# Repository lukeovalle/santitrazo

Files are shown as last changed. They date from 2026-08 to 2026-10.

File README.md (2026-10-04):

# Santitrazo
Seguidor de línea usando un atmega328p

## Estructura del directorio
placa/      proyecto de KiCAD
codigo/     código de Arduino
cuerpo/     piezas mecánicas (FreeCAD + STL)

## TODO
 - [ ] describir mejor el proyecto

## Mediciones 
Placa + sensores
    5V 0.9A
    
Motores
    5V  0.3A
    6V  1.3A

## Valores PID
Historial de pruebas. Los valores vigentes en el firmware están en las constantes
`k_prop`, `k_inte` y `k_dif` de `codigo/TaskController.cpp`.

P    | I      | D   | tiempo | pista grande
0.85 | 1e-3   | 6   | 4.6    |
0.9  | 2e-3   | 6   | 4.8    | 28
0.95 | 1.2e-3 | 6.2 | 5.2    |
0.85 | 1e-3   | 6   | --     | 27.88
0.92 | 1.2e-3 | 6.1 | 5.2    |
0.92 | 1.2e-3 | 6.1 | 4.7    | 28.3 (rigidizar ruedas traseras, lubricar placa, bat 7,1 V)
1    | 1.2e-3 | 6.2 | ------ |     (bat 7,8 V)
1.1  | 1.2e-3 | 6.8 | 5.7    |     (bat 7,8 V)
1    | 1.2e-3 | 3   | 4.6    |  (07/08/26 PID cada 10ms, promediado de sensores)
1.05 | 1.2e-3 | 5   | 4.6    | 
1.1  | 1.2e-3 | 6   | 4.4    |
1.1  | 1.5e-3 | 7   | 4.4    |
1.1  | 1.5e-3 | 8   | 4.4    | 24.3  (8.14V)

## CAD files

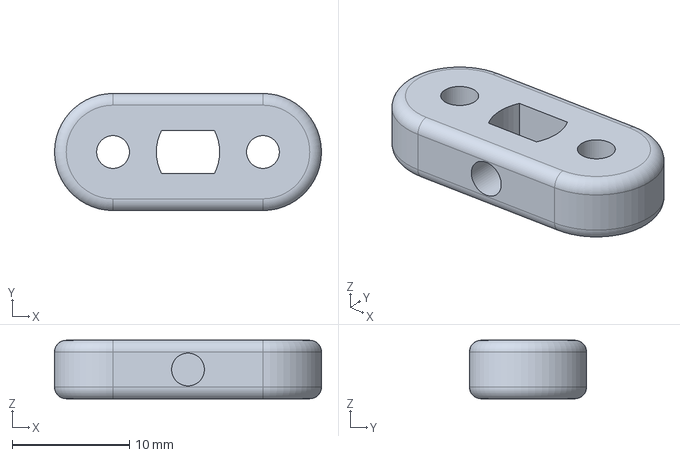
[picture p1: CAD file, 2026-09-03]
cuerpo/adaptador_motor_rueda.FCStd
22.8 x 10.0 x 5.00 mm

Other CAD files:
cuerpo/adaptador_motor_rueda-Body.stl

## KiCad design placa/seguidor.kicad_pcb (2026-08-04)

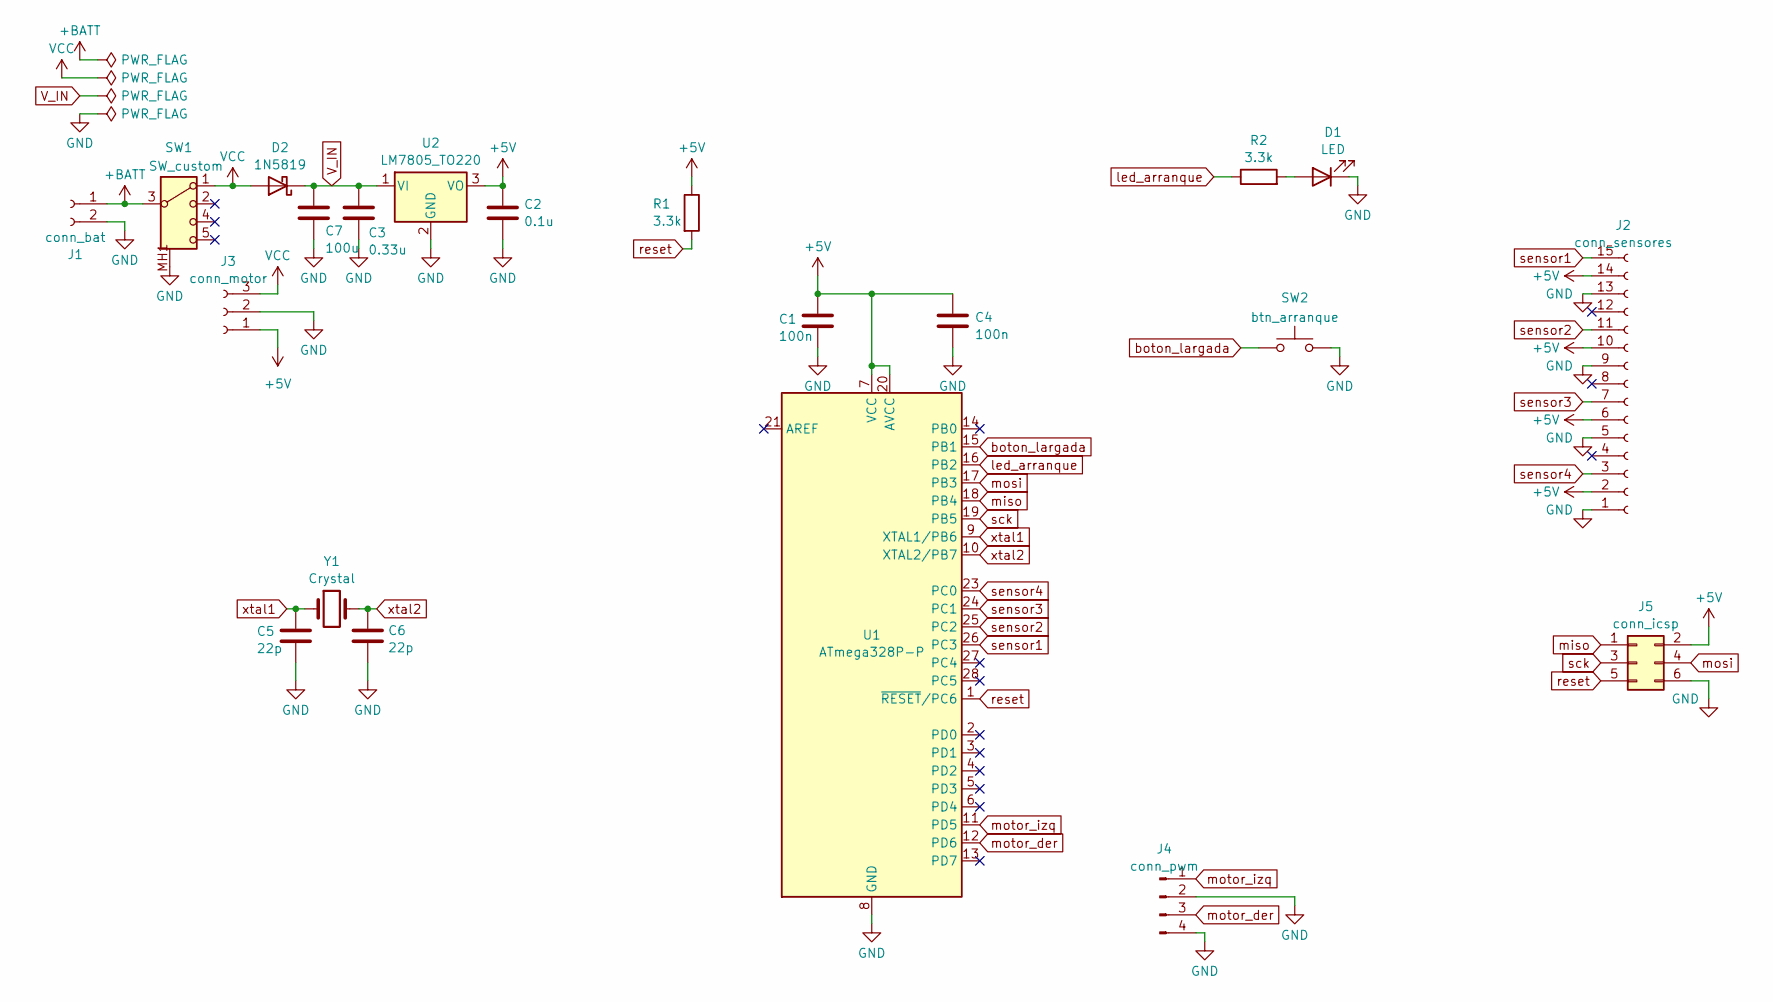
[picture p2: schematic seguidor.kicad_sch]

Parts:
C1, C4: 100n; C_Disc_D6.0mm_W2.5mm_P5.00mm
C2: 0.1u; CP_Radial_D5.0mm_P2.00mm
C3: 0.33u; CP_Radial_D5.0mm_P2.00mm
C5, C6: 22p; C_Disc_D4.7mm_W2.5mm_P5.00mm
C7: 100u; CP_Radial_D5.0mm_P2.00mm
D1: LED; LED_D4.0mm
D2: 1N5819; D_DO-41_SOD81_P10.16mm_Horizontal
J1: conn_bat; Molex_KK-396_A-41791-0002_1x02_P3.96mm_Vertical
J2: conn_sensores; PinSocket_1x15_P2.54mm_Horizontal
J3: conn_motor; Molex_KK-254_AE-6410-03A_1x03_P2.54mm_Vertical
J4: conn_pwm; PinHeader_1x04_P2.54mm_Vertical
J5: conn_icsp; PinHeader_2x03_P2.54mm_Vertical
R1, R2: 3.3k; R_Axial_DIN0204_L3.6mm_D1.6mm_P5.08mm_Horizontal
SW1: SW_custom; Switch custom
SW2: btn_arranque; SW_PUSH_6mm_H5mm
U1: ATmega328P-P; DIP-28_W7.62mm_Socket
U2: LM7805_TO220; TO-220-3_Vertical
Y1: Crystal; Crystal_HC49-4H_Vertical

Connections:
+5V: C1.1, C2.1, C4.1, J2.2, J2.6, J2.10, J2.14, J3.1, J5.2, R1.1, U1.7 (VCC), U1.20 (AVCC), U2.3 (VO)
+BATT: J1.1, SW1.3
GND: C1.2, C2.2, C3.2, C4.2, C5.2, C6.2, C7.2, D1.1 (K), J1.2, J2.1, J2.5, J2.9, J2.13, J3.2, J4.2, J4.4, J5.6, SW1.MH1 (CHASIS), SW1.MH2 (CHASIS), SW2.2, U1.8 (GND), U1.22 (GND), U2.2 (GND)
unnamed: D1.2 (A), R2.2
VCC: D2.2 (A), J3.3, SW1.1
V_IN: C3.1, C7.1, D2.1 (K), U2.1 (VI)
boton_largada: SW2.1, U1.15 (PB1)
led_arranque: R2.1, U1.16 (PB2)
miso: J5.1, U1.18 (PB4)
mosi: J5.4, U1.17 (PB3)
motor_der: J4.3, U1.12 (PD6)
motor_izq: J4.1, U1.11 (PD5)
reset: J5.5, R1.2, U1.1 (~RESET/PC6)
sck: J5.3, U1.19 (PB5)
sensor1: J2.15, U1.26 (PC3)
sensor2: J2.11, U1.25 (PC2)
sensor3: J2.7, U1.24 (PC1)
sensor4: J2.3, U1.23 (PC0)
xtal1: C5.1, U1.9 (XTAL1/PB6), Y1.1
xtal2: C6.1, U1.10 (XTAL2/PB7), Y1.2

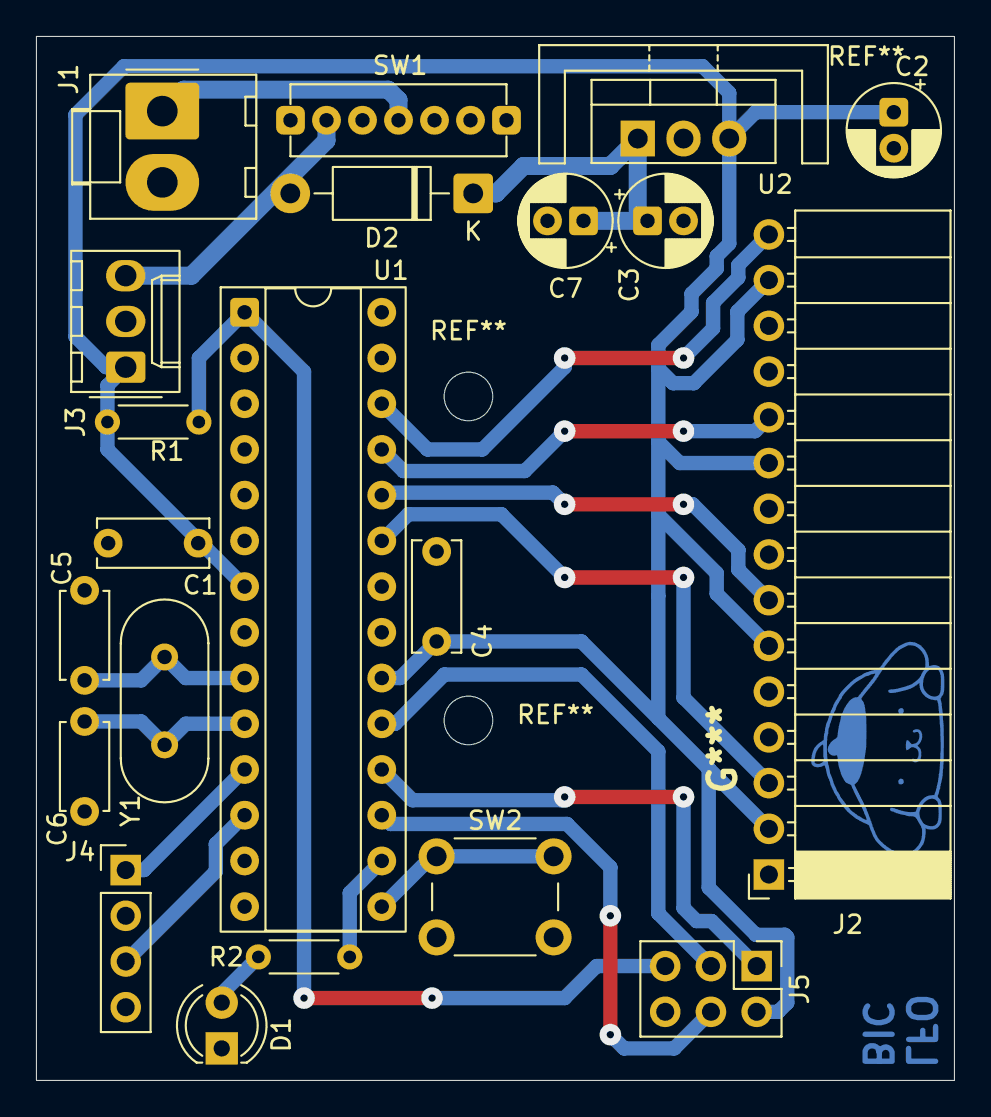
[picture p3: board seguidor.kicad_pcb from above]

Board: 2 copper layers, 51.0 x 58.0 mm, 21 parts (0 on the bottom side), 20 nets.

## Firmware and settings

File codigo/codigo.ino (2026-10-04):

#include "ClockMs.h"
#include "Executor.h"

#include "TaskLED.h"
#include "TaskBoton.h"
#include "TaskSensor.h"
#include "TaskMotor.h"
#include "TaskController.h"

ClockMs reloj; // counts ms between calls (no se llama "clock" para no chocar con clock() de <time.h>)
Executor executor;

// Defino mis tareas
TaskLED led_arranque(10); // PB2
TaskBoton boton_largada(9); // PB1
TaskSensor sensor1(17); // PC3
TaskSensor sensor2(16); // PC2
TaskSensor sensor3(15); // PC1
TaskSensor sensor4(14); // PC0
TaskMotor motor_izq(5); // PD5
TaskMotor motor_der(6); // PD6


controller_contexto contexto = {
  .led_arranque = &led_arranque,
  .boton_largada = &boton_largada,
  .sensores = {&sensor1, &sensor2, &sensor3, &sensor4},
  .motor_izq = &motor_izq,
  .motor_der = &motor_der
};
TaskController controlador(&contexto, 10); // corre cada 10ms

void setup() {
  // Agrego las tareas al ejecutor
  executor.addTask(&led_arranque);
  executor.addTask(&boton_largada);
  executor.addTask(&sensor1);
  executor.addTask(&sensor2);
  executor.addTask(&sensor3);
  executor.addTask(&sensor4);
  executor.addTask(&motor_izq);
  executor.addTask(&motor_der);

  executor.addTask(&controlador);

  Serial.begin(115200);

  reloj.init();
  executor.init();
}

void loop() {
  unsigned long ticks = reloj.pending_ticks();
  executor.increaseTicks(ticks);

  executor.update();
}

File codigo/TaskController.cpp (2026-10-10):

// TaskController.cpp

#include <Arduino.h>
#include "TaskController.h"
#include "utils.h"
#include "TaskLED.h"
#include "TaskBoton.h"
#include "TaskSensor.h"
#include "TaskMotor.h"

static int ticks = 10;

void TaskController::init(void) {
  mState = ST_CONTROLLER_INIT;
  mEvent = EV_CONTROLLER_IDLE;
  mBotonAnterior = false;
  _reiniciarPID();
}

// Borra la memoria del PID (integral y error previo) para que una corrida
// nueva no arrastre el estado de la anterior.
void TaskController::_reiniciarPID(void) {
  mPrevError = 0;
  mAcumIntegralError = 0;
}

void TaskController::update(void) {
  // Veo si se apretó el botón y si antes no estaba presionado.
  bool boton = mTareas->boton_largada->estaPresionado();

  if (!mBotonAnterior && boton)
    mEvent = EV_CONTROLLER_BUTTON_PRESSED;

  mBotonAnterior = boton;

  _statechart();
}


void TaskController::_statechart(void) {
  switch (mState) {
  case ST_CONTROLLER_INIT:
    if (mEvent == EV_CONTROLLER_BUTTON_PRESSED) {
      _reiniciarPID();
      mTareas->led_arranque->encender();
      mTareas->motor_izq->encender();
      mTareas->motor_der->encender();
      mState = ST_CONTROLLER_RUNNING;
    }
    break;

  case ST_CONTROLLER_RUNNING: {
    if (mEvent == EV_CONTROLLER_BUTTON_PRESSED) {
      mTareas->led_arranque->apagar();
      mTareas->motor_izq->apagar();
      mTareas->motor_der->apagar();
      mState = ST_CONTROLLER_INIT;
      break;
    }

    // Lógica del PID
    int pid = _calcularPID();

    int vel_max = 255; // valor máximo 255

    // pid > 0: la línea está a la derecha, frena el motor derecho.
    // pid < 0: la línea está a la izquierda, frena el motor izquierdo.
    // Uno suma y el otro resta; el CLAMP de TaskMotor::cambiarVelocidad()
    // mantiene cada velocidad dentro de rango, así que el motor que "suma"
    // se queda en el máximo.
    mTareas->motor_izq->cambiarVelocidad(vel_max + pid);
    mTareas->motor_der->cambiarVelocidad(vel_max - pid);

    break;
  }

  default:
    mState = ST_CONTROLLER_INIT;
    break;
  }

  mEvent = EV_CONTROLLER_IDLE;
}

int TaskController::_calcularPID(void) {
  const float k_prop = 1.3,
              k_dif = 13,
              k_inte = 1.3e-2;

  float error = _calcular_error();

  // parte proporcional
  float prop = k_prop * error;

  // parte integral
  mAcumIntegralError += error;
  mAcumIntegralError = CLAMP(mAcumIntegralError, -1e3, 1e3);
  float integral = k_inte * mAcumIntegralError;

  // parte diferencial
  // podría dividir por un dt pero asumo que es constante y "está incluído " en k_dif
  float de_dt = (error - mPrevError);
  float diferencial = k_dif * de_dt;

  ticks--;
  if (!ticks) {
    Serial.print(prop);
    Serial.print(",");
    Serial.print(integral);
    Serial.print(",");
    Serial.println(diferencial);
    ticks = 10;
  }

  mPrevError = error;
  return (int)(prop + integral + diferencial);
}

float TaskController::_calcular_error(void) {
  static const float sensores[] = { -200, -100, 100, 200 }; // Pesos de cada sensor
  float suma = 0;
  float activos = 0;

  for (int i = 0; i < TAM_SENSORES; i++) {
    float activo = mTareas->sensores[i]->nivelActividad();
    suma += sensores[i] * activo; // multiplico por el valor sensado en rango [0, 1]
    activos += activo;
  }

  // si no se leyeron sensores, uso el último valor así sigue doblando hasta volver a la línea
  if (activos < 0.01f)
    return mPrevError;

  return suma / activos; // promedio
}

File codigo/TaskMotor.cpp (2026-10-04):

// TaskMotor.cpp
#include "Arduino.h"
#include "TaskMotor.h"
#include "utils.h"

void TaskMotor::init(void) {
  mState = ST_MOTOR_OFF;
  mEvent = EV_MOTOR_IDLE;
  mVel = 0;
  pinMode(mPin, OUTPUT);
}

void TaskMotor::update(void) {
  _statechart();
}

void TaskMotor::apagar(void) {
  mEvent = EV_MOTOR_TURN_OFF;
}

void TaskMotor::encender(void) {
  mEvent = EV_MOTOR_TURN_ON;
}

void TaskMotor::cambiarVelocidad(int vel) {
  mEvent = EV_MOTOR_CHANGE_VELOCITY;
  mVel = CLAMP(vel, 0, 255);
}

void TaskMotor::_statechart(void) {
  switch (mState) {
  case ST_MOTOR_OFF:
    if (mEvent == EV_MOTOR_TURN_ON) {
      _encenderPWM();
      mState = ST_MOTOR_ON;
    }
    break;

  case ST_MOTOR_ON:
    if (mEvent == EV_MOTOR_TURN_OFF) {
      _apagarPWM();
      mState = ST_MOTOR_OFF;
    } else if (mEvent == EV_MOTOR_CHANGE_VELOCITY) {
      _encenderPWM();
    }
    break;

  default:
    mState = ST_MOTOR_OFF;
    _apagarPWM();
    break;
  }

  mEvent = EV_MOTOR_IDLE;
}

void TaskMotor::_encenderPWM(void) {
  analogWrite(mPin, mVel);
}

void TaskMotor::_apagarPWM(void) {
  // Pongo mVel en 0 para que al volver a encender el motor no arranque
  // con la última velocidad de la corrida anterior.
  mVel = 0;
  analogWrite(mPin, 0);
}

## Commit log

2026-04-17 Circuito iniciado
    [seguidor.kicad_pcb, seguidor.kicad_sch]
2026-04-19 circuito modificado
    [seguidor.kicad_pcb, seguidor.kicad_sch]
2026-04-20 código para un LED
2026-04-20 agregados componentes al pcb, faltan conectores
    [seguidor.kicad_pcb, seguidor.kicad_sch]
2026-04-23 cambiados capacitores en la placa
    [seguidor.kicad_pcb, seguidor.kicad_sch]
2026-05-09 Tamaño de la placa y agujeros
    [seguidor.kicad_pcb]
2026-05-11 Task LED en el código
2026-05-16 conector de 3 pines para el puente H
    [seguidor.kicad_sch]
2026-05-29 placa editada
    [seguidor.kicad_pcb, seguidor.kicad_sch]
2026-06-11 tareas botón y led implementadas
2026-06-12 tareas de motor y sensor implementadas
2026-07-24 placa: agrego conector ICSP, protección de alimentación, botón de reset
    [seguidor.kicad_pcb, seguidor.kicad_sch]
2026-07-25 editados valores del PID
2026-07-30 placa reordenada y conector spi
    [seguidor.kicad_pcb, seguidor.kicad_sch]
2026-08-04 pins cambiados. PID ajustado. mensajes de debug.
    [seguidor.kicad_pcb, seguidor.kicad_sch]
2026-08-07 PID ajustado
2026-08-07 cada tarea se ejecuta con su propio contador de ticks. los sensores promedian las últimas mediciones
2026-08-08 PID ajustado. mas suavizado de mediciones
2026-09-03 modelo 3D y .stl del adaptador entre ruedas nuevas y motores
    [adaptador_motor_rueda-Body.stl, adaptador_motor_rueda.FCStd]
2026-10-04 Corrige bugs de reinicio y compilación detectados en la auditoría
    - TaskController: el `case ST_CONTROLLER_RUNNING` declaraba variables
    inicializadas sin llaves, lo que no compila con g++ moderno (error
    "jump to case label", ni siquiera con -fpermissive). Agrego llaves.
    - TaskController: al arrancar una nueva corrida se reinician la integral
    y el error previo. Antes quedaba un sesgo fijo en el PID (integral
    vieja) y un pico del derivativo al volver a largar.
    - TaskMotor: _apagarPWM() pone mVel en 0 para que al volver a encender
    el motor no arranque con la última velocidad de la corrida anterior.
    - Executor::addTask: verifica N_TASKS para no escribir fuera del arreglo
    (ahora de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
    [TaskController.cpp, TaskLED.cpp, TaskMotor.cpp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]
2026-10-05 Simplifica la mezcla del PID: uno suma y el otro resta
    Reemplaza el if/else sobre el signo del PID por
    motor_izq = vel_max + pid
    motor_der = vel_max - pid
    El CLAMP de TaskMotor::cambiarVelocidad() deja cada velocidad en [0, 255],
    así que el motor que "suma" queda en el máximo y el que "resta" baja,
    exactamente igual que antes (incluido pid == 0).
    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
2026-10-05 Agrega marcha atrás a los motores (puente H con IN1/IN2)
    - TaskMotor ahora recibe (pin PWM, IN1, IN2, invertido = false). La
    velocidad pasa a estar en [-255, 255]: el signo elige el sentido
    (adelante: IN1 alto / IN2 bajo; atrás: al revés) y el módulo es el PWM.
    Al apagar quedan PWM = 0 e IN1 = IN2 = LOW.
    - codigo.ino: pines de dirección tentativos (motor izq: IN1 = D2,
    IN2 = D4; motor der: IN1 = D7, IN2 = D8), a ajustar según el cableado.
    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
2026-10-10 Motores con 2 PWM por motor: freno activo con velocidad 0
    TaskMotor pasa a recibir (pinAdelante, pinAtras, invertido = false) y se
    usa con ENA/ENB del L298N siempre en alto (jumper puesto):
    vel > 0: PWM en pinAdelante, pinAtras = 0
    vel < 0: PWM en pinAtras, pinAdelante = 0
    vel = 0: ambos en 0, o sea IN1 = IN2 = LOW con enable alto = freno activo
    Como la parte apagada del PWM tambien es freno (y no rueda libre), el
    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
2026-10-17 Pines de motores para la placa actual (PD5/PD6 + PD3/PB3)
    Los pines que ya tenian PWM (PD5 y PD6, pines 11 y 12 del DIP-28) quedan
    como "adelante"; los IN que antes iban a tierra pasan a PD3 (pin 5, sin
    uso en el esquema) y PB3 (pin 17, compartido con MOSI del ICSP) como
    "atras":
    motor_izq(5, 3) - adelante PD5, atras PD3
    motor_der(6, 11) - adelante PD6, atras PB3
    Solo cambian los argumentos de los constructores. Verificado con la
    misma simulacion en el host: velocidades con signo identicas a
    motores-reversa (120840 comparaciones, 0 diferencias) y nunca PWM en los
    dos sentidos de un motor a la vez.
    Claude-Session: https://claude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
2026-10-22 ajustado PID, preparaciones para código de turbo
2026-10-23 código compila. ajustado PID
2026-10-23 Corrige turbo: el contador nunca incrementaba (== en vez de <=)
    El contador mTurboTicks arranca en 0 y solo se incrementaba si valía
    exactamente TURBO_TICKS_DURACION, así que nunca salía de 0 y el turbo
    no se activaba. Ahora incrementa mientras sea <= DURACION y satura en
    DURACION + 1, dejando el turbo en 2 s a partir del segundo de recta.
    Claude-Session: https://claude.ai/code/session_015AR18Ye6d6h3dFfMxCwrnE
2026-10-23 Limpieza de código y ajuste de tiempos de turbo
2026-10-24 ajustes para la pista
